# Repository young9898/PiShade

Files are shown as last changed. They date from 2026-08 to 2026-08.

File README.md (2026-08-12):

# PiShade

A motorized roller shade driven by a Raspberry Pi and a stepper motor, so a
cheap pull-down shade opens and closes on solar time instead of on somebody
remembering to pull the cord.

Built in January 2019 for a room with houseplants and an aquarium that wanted a
consistent daily light cycle. Nothing in it is specific to that room — it is a
stepper turning a roller a fixed number of steps, twice a day. It picked up the
name PiShade in 2021, when this repository was created.

> **Note on the code:** the original scripts were never committed. What is here
> is a **reconstruction** written in 2026 from the original build notes. The step
> counts, the mechanism, and the cron schedule are the real ones. The code is
> new, written against the documented library API rather than recovered.

## How it works

A NEMA 17 stepper turns the shade's roller through an Adafruit Motor HAT on
the Pi's GPIO header. Two cron jobs run the shade to its limit in each
direction. There are no limit switches and no encoder — the travel is a step
count that was calibrated once and has not needed to change.

## The calibration, and why it is 3200

A NEMA 17 is 1.8° per step, so 200 full steps per revolution. The Adafruit
library's `INTERLEAVE` style doubles the resolution to **400 steps per
revolution**; `MICROSTEP` at the library's default of 8 gives 1600.

The original calibration was done by taping a mark on the roller, stepping the
motor, and counting until the mark came back around. That produced "about 428
steps per rotation" — 7% over the true 400, which is exactly what counting to a
visual mark with a little slop in the drive looks like.

Full travel was then set at **3200 steps**, picked because it was a tidy round
number. It happens to land on **exactly 8.0 revolutions**, and at the measured
~1.6 inches of shade per revolution that is roughly **12.8 inches** of travel.
A separate note in the build log — 4000 microsteps ≈ 4 inches — is the same
geometry seen through the 1600-steps/rev microstep mode, and agrees.

The lesson worth keeping: the sloppy hand calibration was 7% wrong, and it did
not matter, because the number that got used was rounded to something the
mechanism could absorb. Shades are forgiving. Do not build an encoder for this.

### Interleave vs. microstep

`INTERLEAVE` was chosen over `MICROSTEP` deliberately. Microstepping buys
smoothness and resolution that a window shade has no use for, at the cost of
4× the steps for the same travel and less torque per step. Interleave has
enough torque to overcome the shade's static friction on startup, which is the
only hard moment in the cycle.

## Scheduling

The original schedule was plain fixed-time cron:

```cron
0 17 * * * /usr/bin/python3 /home/pi/PiShade/motor_down.py
0  8 * * * /usr/bin/python3 /home/pi/PiShade/motor_up.py
```

Fixed times drift badly against the actual sun across a year. The better
version uses [`sunwait`](https://github.com/risacher/sunwait), which blocks
until sunrise or sunset at a given latitude/longitude:

```cron
# Substitute your own coordinates. Two decimal places is plenty — the sun does
# not care, and six decimals pins a residence to the centimetre.
0 4 * * * sunwait wait rise 00.00N 000.00W && /usr/bin/python3 /home/pi/PiShade/motor_up.py
0 15 * * * sunwait wait set 00.00N 000.00W && /usr/bin/python3 /home/pi/PiShade/motor_down.py
```

Check `sunwait`'s own docs for the exact argument form on your build; it also
supports civil-twilight offsets, which are usually what you actually want for a
shade rather than true sunrise.

## Parts

| Part | Notes |
|---|---|
| Raspberry Pi | Any model with the 40-pin header |
| Adafruit Motor HAT (or DC+Stepper HAT) | Stepper terminal 1 |
| STEPPERONLINE NEMA 17 stepper | 26 N·cm (36.8 oz-in), 12 V, 0.4 A/phase |
| 12 V supply for the HAT | Separate from the Pi's own supply |
| Roller shade | An inexpensive hardware-store pull-down |
| 3D printed parts | Motor mount and a coupler to the roller tube |

The 26 N·cm motor is generously sized for this. Shade torque is dominated by
static friction at startup, not by the weight of the fabric.

## Printed parts

The three parts that were actually installed, in `models/`. These are the
as-printed 2019 STLs, not a re-modelled set — there is no CAD source, only the
mesh.

| File | Size | Notes |
|---|---|---|
| `models/roller_hub.stl` | Ø31.3 × 21.8 mm | Drives the roller tube. Ø31.3 is a slip fit into a nominal 1¼ in (31.75 mm) tube; check yours with calipers, tubes vary. |
| `models/motor_bracket.stl` | 66.4 × 57.5 × 55.2 mm | Carries the NEMA 17 at the driven end. |
| `models/end_bracket.stl` | 81.4 × 61.8 × 45.4 mm | Idler end, opposite the motor. |

The hub took four revisions to fit — Ø46.5, then 33.3, then 31.3 — which is the
usual story of measuring a tube's inside diameter by eye and then by caliper.
Printed in PLA at 0.2 mm layers, 20% infill; the hub was run at 0.08 mm and 80%
because it is the part that transmits all the torque.

Dimensions above were measured off the original toolpaths, not read from a
model tree. Print one, check it against your own hardware before committing to
the pair.

## Running it

```bash
pip3 install adafruit-circuitpython-motorkit
python3 shade.py up --dry-run     # prints the move, touches no hardware
python3 shade.py down             # full travel
python3 shade.py up 400           # one revolution, for calibration
```

`shade.py` imports the Adafruit stack lazily, so `--dry-run` works on a laptop.
The motor is released after every move — a stepper held at standstill draws
full rated current and gets hot for no benefit, and friction holds the shade
fine.

## Attribution

The 2019 original was adapted from the `StepperTest.py` example in
[adafruit/Adafruit-Motor-HAT-Python-Library](https://github.com/adafruit/Adafruit-Motor-HAT-Python-Library).
That repository is archived and carries **no license file**, so none of its
code is reproduced here — this implementation was written fresh against the
API. Credit for the original approach belongs to Adafruit.

For anything new, use Adafruit's modern MIT-licensed replacement,
[`adafruit-circuitpython-motorkit`](https://github.com/adafruit/Adafruit_CircuitPython_MotorKit),
which is what the code here targets.

## License

MIT — see [LICENSE](LICENSE). Relicensed from GPL-3.0 in 2026; copies
distributed under the earlier license remain under it.
No strings beyond the license file, and no policing. If this saves you an
afternoon, that is the whole point. Credit is appreciated and never demanded; if
you build something better on top of it, that is the best outcome available.

## Contact

github@youngnetwork.org

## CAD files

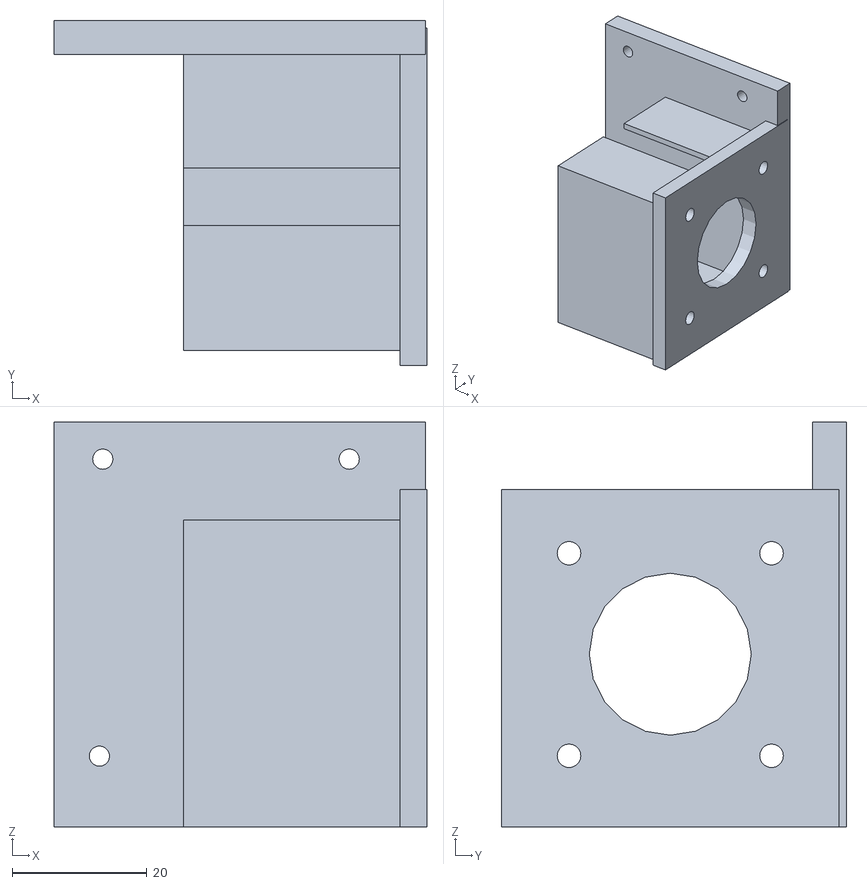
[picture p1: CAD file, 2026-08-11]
models/motor_bracket.stl
55.2 x 51.1 x 60.0

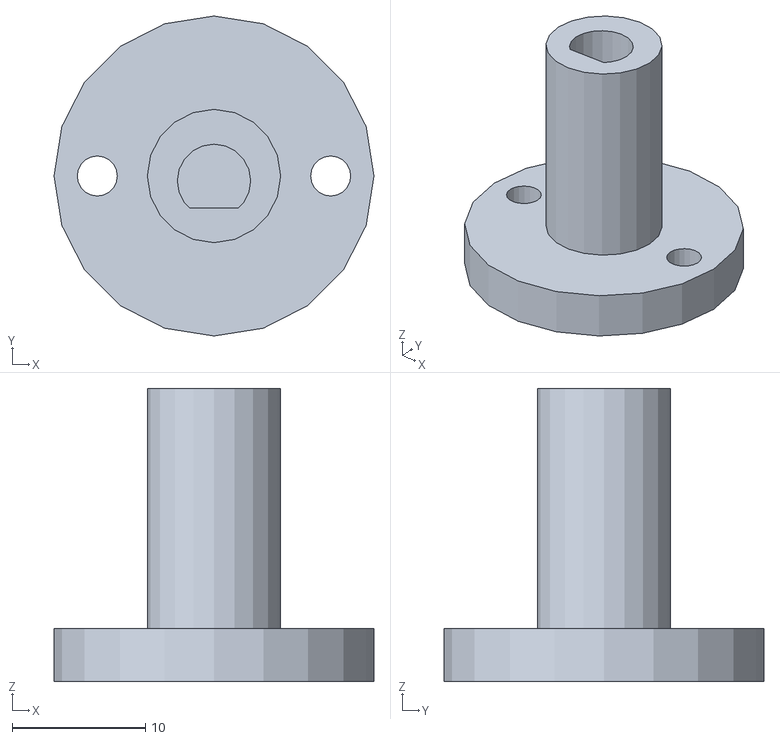
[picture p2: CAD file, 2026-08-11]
models/roller_hub.stl
24.0 x 24.0 x 22.0

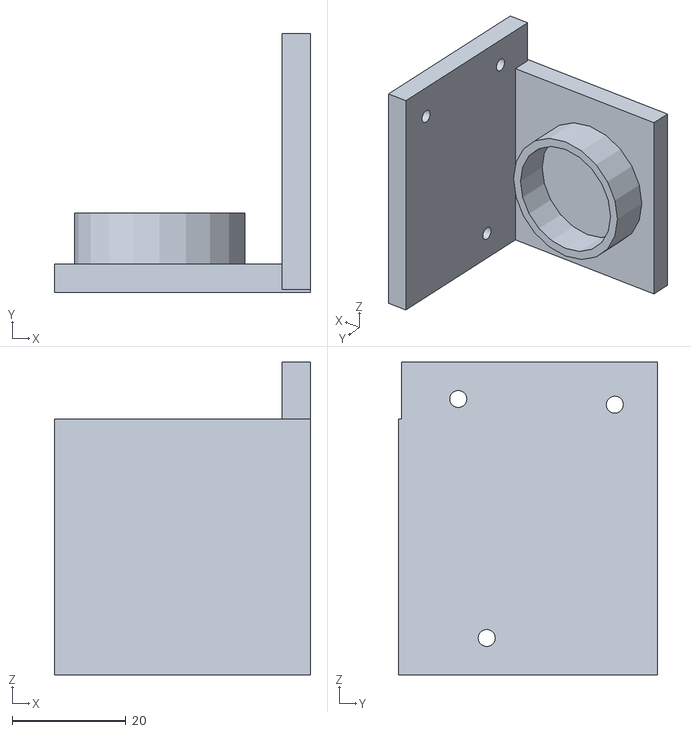
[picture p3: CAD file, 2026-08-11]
models/end_bracket.stl
45.0 x 45.5 x 55.0

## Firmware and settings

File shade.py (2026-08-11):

"""PiShade — drive a roller shade from a Raspberry Pi stepper motor.

SUBJECT: motion control for a roller-shade roller driven by a NEMA 17 stepper
through an Adafruit Motor HAT; travel constants below were calibrated by
counting steps against a mark on the roller, not by CAD.

Reconstruction (2026) of a 2019 script that was not kept under version
control. The step counts and the cron schedule are from the original notes;
the code itself is new, written against the documented MotorKit API.
"""

import atexit
import sys

# --- Calibration -----------------------------------------------------------
# A NEMA 17 is 1.8 deg/step -> 200 full steps per revolution.
# INTERLEAVE doubles that to 400 steps/rev; MICROSTEP (8x) gives 1600.
STEPS_PER_REV_FULL = 200
STEPS_PER_REV_INTERLEAVE = STEPS_PER_REV_FULL * 2

# Full travel, measured on the installed shade: 8 revolutions of the roller.
TRAVEL_STEPS = 3200                      # = 8.0 rev in INTERLEAVE
INCHES_PER_REV = 1.6                     # roller circumference, measured
TRAVEL_INCHES = TRAVEL_STEPS / STEPS_PER_REV_INTERLEAVE * INCHES_PER_REV

STEPPER_PORT = 1                         # Motor HAT stepper terminal 1/2
STEP_DELAY_S = 0.005                     # ~200 steps/s; slow enough not to stall


def _hardware():
    """Import the Adafruit stack lazily so the module is importable off-Pi."""
    from adafruit_motorkit import MotorKit
    from adafruit_motor import stepper

    kit = MotorKit()
    motor = kit.stepper1 if STEPPER_PORT == 1 else kit.stepper2
    atexit.register(motor.release)
    return motor, stepper


def move(direction, steps=TRAVEL_STEPS, dry_run=False):
    """Run the roller `steps` interleaved steps in 'up' or 'down'.

    The motor is always released on exit. A stepper left energised at a
    standstill draws its full rated current and gets hot; nothing about a
    shade needs holding torque, gravity and friction hold it fine.
    """
    if direction not in ("up", "down"):
        raise ValueError("direction must be 'up' or 'down'")

    revs = steps / STEPS_PER_REV_INTERLEAVE
    print(f"{direction}: {steps} steps = {revs:.2f} rev "
          f"= {revs * INCHES_PER_REV:.1f} in")
    if dry_run:
        return

    import time

    motor, stepper = _hardware()
    sense = stepper.FORWARD if direction == "up" else stepper.BACKWARD
    try:
        for _ in range(steps):
            motor.onestep(direction=sense, style=stepper.INTERLEAVE)
            time.sleep(STEP_DELAY_S)
    finally:
        motor.release()


def main(argv):
    if len(argv) < 2 or argv[1] not in ("up", "down"):
        print("usage: shade.py {up|down} [steps] [--dry-run]", file=sys.stderr)
        return 2
    steps = TRAVEL_STEPS
    for arg in argv[2:]:
        if arg != "--dry-run":
            steps = int(arg)
    move(argv[1], steps, dry_run="--dry-run" in argv)
    return 0


if __name__ == "__main__":
    sys.exit(main(sys.argv))

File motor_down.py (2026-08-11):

#!/usr/bin/env python3
"""Lower the shade its full travel. Called from cron at sunset.

SUBJECT: cron entry point for the roller shade; travel constants live in
shade.py, which documents where they were measured.
"""

import sys

from shade import move

if __name__ == "__main__":
    move("down", dry_run="--dry-run" in sys.argv)

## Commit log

2026-08-11 Reconstruct the shade controller, relicense to MIT
    The 2021 scripts were never committed. This is a reconstruction written
    against the documented MotorKit API from the original build notes: 3200
    interleaved steps of full travel, which is exactly 8.0 revolutions of the
    roller at 400 steps/rev, about 12.8 inches of shade.
    Adds shade.py (calibration constants and move logic, hardware imported
    lazily so --dry-run works off-Pi) and motor_up.py / motor_down.py as cron
    entry points. The motor is released after every move.
    Rewrites the README around the mechanism, the hand calibration and why
    its 7% error did not matter, the interleave-vs-microstep tradeoff, and
    solar scheduling with sunwait inste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
    [motor_down.py, motor_up.py, shade.py]
2026-08-11 Correct the build date to 2019
    The printed parts — the roller hub and the motor brackets — were sliced
    between 11 and 18 January 2019. The project only took the name PiShade in
    2021, when this repository was created. Copyright year follows the build.
    [shade.py]
2026-08-11 Add the printed parts
    The as-printed 2019 meshes for the roller hub and the two brackets. There is
    no CAD source for these — the STL is the artifact — so they are published as
    they came off the slicer's input side, renamed for legibility.
    Documents the sizes, the print settings, and the four revisions the hub took
    to fit the roller tube. Committed with --no-verify: the publish gate blocks
    all binaries on principle because it cannot read one. Adjudicated by hand
    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
    [end_bracket.stl, motor_bracket.stl, roller_hub.stl]
